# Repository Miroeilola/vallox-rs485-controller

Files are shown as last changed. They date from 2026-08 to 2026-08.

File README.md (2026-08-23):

# Vallox RS-485 Controller

Replacement bus controller for legacy Vallox ventilation units.

<p align="center">
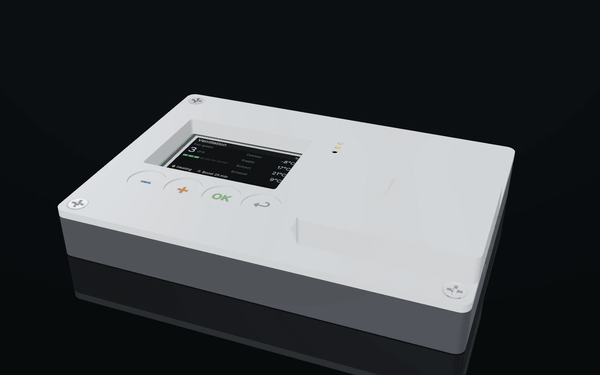
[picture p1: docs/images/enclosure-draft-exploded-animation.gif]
Exploded-view animation: four screws, the cover, the rev A board with the live panel UI, and the base tray separate and reassemble while the camera orbits. A render, not a photograph.
  
</p>

*Render of the rev A board inside the parametric enclosure draft — not a photograph;
one replaces this when a device has been built. Stills in [`docs/images/`](docs/images/),
the [browser simulator](https://miroeilola.github.io/vallox-rs485-controller/) shows
the same board live, and the enclosure draft is generated by
[`mechanical/draft/`](mechanical/draft/).*

<!-- Replace the animation with a photo of the finished device once one exists. -->







> **Status: hardware, rev A.** The board is drawn, placed, routed and sourced —
> not yet ordered or built. The supply-rail measurements (M1, M2a) are done and
> the power stage is final; the browser simulator runs the panel firmware's real
> UI core as WebAssembly; the enclosure exists as a parametric draft that Fusion
> 360 will supersede. Nothing has been verified against a real machine yet. What
> is known, what is only reported, and what still has to be measured is written
> down in [`docs/research/`](docs/research/) and [`docs/measurements/`](docs/measurements/).

## What this replaces

Vallox has built residential heat-recovery ventilation units in Finland since the
1970s, and the SE-series machines are still in service in tens of thousands of
houses. The machine outlives its control panel: the mechanics and the heat exchanger
last decades, the panel's keypad and its electrolytics do not, and panels for the
older models are no longer made.

The machines already carry an RS-485 bus, and everything the panel shows — four
temperatures, fan speed, humidity, CO₂, fault and service state — travels over it
in a six-byte telegram. **This board takes the panel's place**: same five
terminals, same wall, no other hardware, and the machine appears in Home Assistant
or MQTT with no manufacturer cloud service in between.

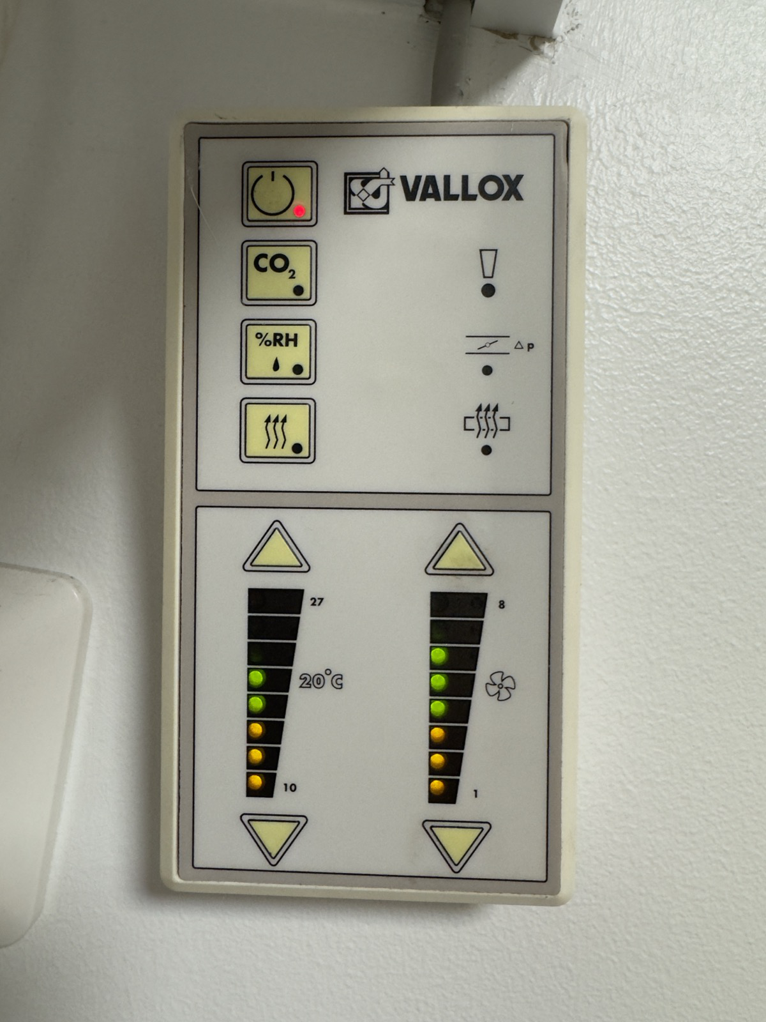
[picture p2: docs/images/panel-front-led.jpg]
The Vallox LED panel being replaced


It is a replacement rather than an addition because the bus does not allow the
addition. The manual says up to three panels may share the bus, and three *Vallox*
panels do — the mainboard keeps them in step. A client that polls on its own
schedule does not join that: tested on the target machine, two controllers override
each other. So the old panel comes off.

That has a consequence worth stating up front, before anyone builds one: **once the
panel is gone, this device is how the ventilation gets controlled.** The machine
keeps running at its last setting if the device fails, and every safety function —
frost protection, over-temperature, defrost — stays in the machine's own firmware
where this device cannot reach it. But nothing changes the fan speed until the
device is working again. Keep the original panel in a drawer.

## Try it in the browser



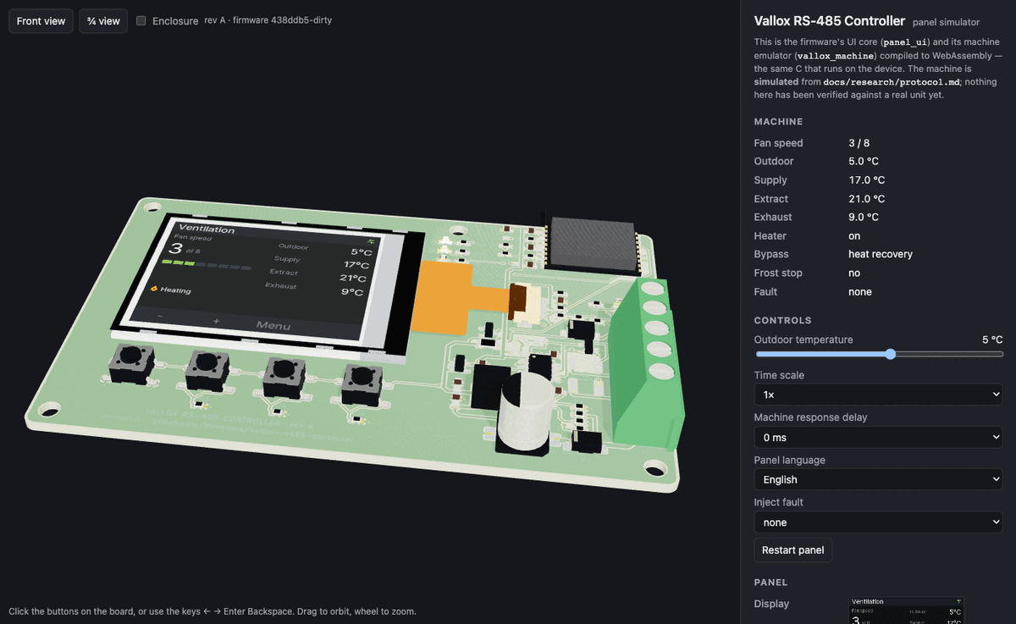
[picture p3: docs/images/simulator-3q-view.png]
Screenshot of the browser simulator: the rev A board rendered from KiCad's 3D export, the panel's dashboard on its display, and the machine side panel. A render, not a photograph.


**https://miroeilola.github.io/vallox-rs485-controller/** — the panel firmware's UI
core and its machine emulator compiled to WebAssembly, drawn on the rev A board's
3D model. Click the buttons, change the outdoor temperature, inject a fault,
watch the bus log, and tick **Enclosure** to see the board inside the draft case. It is the same C that will run on the device
(`firmware/components/panel_ui`), not a look-alike.

The machine behind it is **simulated** from [`docs/research/protocol.md`](docs/research/protocol.md)
and nothing in it has been verified against a real unit yet; the first bus capture
(M3) corrects the document, then the emulator, then the UI. Details and the build
in [`simulator/README.md`](simulator/README.md).

### This is not the first attempt, and that is worth saying

Several people have solved the software side, and solved it well —
[pvainio](https://github.com/pvainio/vallox-rs485),
[kotope](https://github.com/kotope/valloxesp),
[windkh](https://github.com/windkh/valloxserial),
[pecca](https://github.com/pecca/vallox_control),
[mld18](https://github.com/mld18/ioBroker.valloxSerial) and
[Tom-Bom-badil](https://github.com/Tom-Bom-badil/home-assistant_helios-vallox).
The register map here comes from reading their work and is credited in
[`docs/research/sources.md`](docs/research/sources.md).

What none of them ships is hardware. The usual build is a development board, an
RS-485 breakout and a step-down module, loose inside the machine's cable box. This
project adds the missing half: one board that lands on the panel terminals, survives
the wiring mistake the manufacturer warns about in bold, a measured protocol
description with oscilloscope captures rather than a register map you have to read
out of source code, published measurements, an enclosure and a datasheet.

## Specifications

| | |
|---|---|
| Microcontroller | not fixed — ESP32-C3 proposed, see `hardware/docs/decisions.md` |
| Supply voltage | 22 V DC measured at the panel terminal; range not yet measured |
| Current consumption | — (measured, see `docs/measurements/`) |
| Interfaces | RS-485 half duplex, 9600 8N1, Vallox DIGIT protocol · Wi-Fi 2.4 GHz |
| Local interface | 2.0" 320×240 colour IPS, 4 buttons, 3 indicator LEDs — proposed, see `docs/research/user-interface.md` |
| Mounting | Under the machine, replacing the original panel. No footprint to match |
| Dimensions | — |
| Operating temperature | — |
| Enclosure | — |

Every number in this table comes from a measurement or a component datasheet.
Values still marked `—` have not been measured yet.

## Repository layout

| Path | Contents |
|---|---|
| `hardware/` | KiCad 10 project, manufacturing outputs, order packages |
| `firmware/` | ESP-IDF application and reusable components |
| `esphome/` | ESPHome external component (Home Assistant users start here) |
| `simulator/` | Browser simulator: the UI core and machine model in WebAssembly on the board's 3D model |
| `mechanical/` | Enclosure: STEP source, STL for printing, drawings, print profiles |
| `docs/` | Research, measurements, datasheet, images |

## Building one

### 1. Order the board

```bash
git clone --recurse-submodules https://github.com/Miroeilola/vallox-rs485-controller.git
```

Manufacturing files for the released revision are attached to the GitHub release.
The frozen package that was actually sent to the fab is in
`hardware/orders/<rev>-<date>/`, together with what it cost and how long it took.

### 2. Print the enclosure

The enclosure is currently a **parametric draft** ([`mechanical/draft/enclosure.py`](mechanical/draft/enclosure.py)
→ STEP in [`mechanical/step/`](mechanical/step/)), dimensioned from the board file
and verified against the populated 3D model by a boolean interference check —
Fusion 360 will supersede it as the master. See
[`mechanical/README.md`](mechanical/README.md) for material, print settings and
hardware (screws, heat-set inserts).

### 3. Flash the firmware

```bash
cd firmware
idf.py set-target esp32s3
idf.py build flash monitor
```

Pre-built binaries are attached to each release.

### Home Assistant

See [`esphome/`](esphome/) for the external component and a working example
configuration.

## Measurements

Every claim in this repository is backed by a measurement in
[`docs/measurements/`](docs/measurements/): current consumption per operating mode,
rail voltages and ripple, bus signal integrity, and temperature under load.

One report exists so far — the target panel identified and the bus supply measured
at 22 V. It is published with its own gaps marked: the instrument was not recorded
and the load state was not recorded, which is why the regulator's input range is
still an open question rather than a specification.

## What this does not do

- **The display idles dimmed**, and goes to full brightness on a button press.
  Three indicator LEDs stay lit for power, bus activity and fault, and they are
  what answers "is it running" from the doorway.
- **The board works with the display unplugged.** The display is a separate part
  that plugs into an FPC connector after assembly, so a failed or unfitted display
  never means a dead device.
- **Home Assistant is the primary interface.** The local menu covers fan speed,
  the setpoints and diagnostics, and it is a fallback rather than the main event.
- **It is not a safety device and it is not in any safety path.** The machine's
  frost protection, over-temperature thermostats and defrost cycle are in the
  machine's own firmware. This device cannot reach them and cannot disable them.
- **It does not support Vallox MV.** Those units use Modbus and have their own
  interface. This is for the legacy DIGIT RS-485 bus only.
- **It does not support Vallox 130 D** without changes — that model is reported to
  use different register numbers, and no capture from one exists here.
- **It will claim support only for machines a capture exists from.** Other SE-series
  models and Helios KWL EC/ET units are reported to use the same bus, and reported is
  not the same as verified. Which registers a given machine answers is a property of
  that machine.
- **It does not write registers that have not been verified on hardware.** The
  firmware carries an explicit allow-list, it starts with one entry, and a register
  joins it only when a measurement report exists for it. Vallox warns that writing an
  incorrect register or value can damage the unit.
- **It makes no safety or IP-rating claim.** Nothing has been tested for either.
- **Connecting anything to the machine voids the manufacturer's warranty** and is
  your decision, not this project's.

## The machine this was built against

| | |
|---|---|
| Panel replaced | Vallox DIGIT SE LED panel, two 8-segment bar graphs, no LCD |
| Panel bus transceiver | MAX487 — 1/4 unit load, slew-rate limited |
| Terminal | 5-pole screw, `+ − A B M` |
| Supply measured | 22 V DC |
| Machine model | not yet recorded |

Full write-up with photographs:
[`docs/measurements/2026-08-21-panel-identification.md`](docs/measurements/2026-08-21-panel-identification.md).

**Do not wire by colour.** The manufacturer's manual specifies an orange-and-white
NOMAK cable. The machine this was built against has red, blue, green, yellow and
white in those same five terminals. Identify the terminals on your own machine.

## Tools

[`scripts/vlx-decode`](scripts/vlx-decode/) decodes a raw bus capture into
annotated telegrams and a census of the bus. It shares the codec with the
firmware, so it cannot drift from what the device believes.

```bash
cd scripts/vlx-decode && make && ./vlx-decode --demo
```

## Research

Everything known before the design started, with sources and confidence ratings, is
in [`docs/research/`](docs/research/): the
[protocol](docs/research/protocol.md) and its register map, the
[target device](docs/research/target.md) and its panel pinout, the
[measurement plan](docs/research/measurement-plan.md) that has to run before a
schematic is drawn, the [risks](docs/research/risks.md), and the
[component candidates](docs/research/component-candidates.md) with live stock and
prices.

## License

| Path | License |
|---|---|
| `firmware/`, `esphome/`, `scripts/`, `simulator/` | [MIT](LICENSES/MIT.txt) |
| `hardware/`, `mechanical/` | [CERN-OHL-S-2.0](LICENSES/CERN-OHL-S-2.0.txt) |
| `docs/`, README, images | [CC-BY-SA-4.0](LICENSES/CC-BY-SA-4.0.txt) |

See [LICENSE.md](LICENSE.md) for details.

## About

Designed and built by Miro Eilola / [Mironet](https://mironet.fi).
Mironet designs embedded devices like this one on commission — electronics,
enclosure and firmware from specification to production. miro@mironet.fi

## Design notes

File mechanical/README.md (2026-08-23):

# Enclosure

**Current state (2026-08-24): parametric draft, not yet taken over by Fusion.**
`draft/enclosure.py` (build123d) generates the two-part shell from the board file:
`step/enclosure-base-draft.step`, `step/enclosure-cover-draft.step`, and
`draft/screws.py` the M3×8 countersunk screw. `draft/export-enclosure-glb.py`
produces `glb/enclosure.glb` for the browser simulator, and `render/` holds the
scene used for the renders and the exploded-view animation in `docs/images/`.
The draft clears every measured component with margins printed by the script;
membrane-button feel, print tolerances and the final look are Fusion-stage work.

**Fusion 360 is the master for this enclosure.** The STEP files here are the
published source; `.f3d` files are not committed because they require Fusion,
while STEP opens in every CAD system.

| File | Purpose |
|---|---|
| `step/` | Source geometry, exported from Fusion |
| `stl/` | Ready to print |
| `drawings/` | Dimensioned PDF drawings |
| `print-profiles/` | Slicer profiles (`.3mf`) used for the published prints |
| `draft/` | Parametric first-pass scripts, superseded once Fusion takes over |
| `change-requests/` | Requested dimensional changes with measured justification |

## Printing

| | |
|---|---|
| Material | PETG |
| Layer height | 0.2 mm |
| Walls / infill | — |
| Supports | — |
| Estimated time | — |
| Printer used | Bambu |

## Assembly hardware

| Item | Size | Quantity |
|---|---|---|
| Heat-set insert | M3 | — |
| Screw | M3 × — | — |

Heat-set inserts rather than screwing directly into plastic: direct threads survive
two or three openings, inserts survive the life of the device.

## Fit checks

Every enclosure revision is checked against the actual board 3D model before it is
printed — collisions, clearances, standoffs, antenna keep-out, thermal path and
cable routing. Results with measured values are in `fit-check-<date>.md`.

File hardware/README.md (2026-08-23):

# Hardware

KiCad 10 project for Vallox RS-485 Controller.

**Status: rev A schematic drawn and ERC clean; rev A placement done, not routed.** The schematic was drawn
on 2026-08-22 ahead of the power-rail measurements (M1, M2a) so that there is
something concrete to review; the power stage is therefore **provisional** and is
marked as such in the title block. What M1/M2a can change: the regulator part
(TPS54202 vs MP2459), the bulk capacitor value, and whether the backlight runs from
a 5 V intermediate rail (as drawn) or a dedicated boost. Everything downstream of
the 3.3 V rail is independent of those measurements. The measurement plan is
[`../docs/research/measurement-plan.md`](../docs/research/measurement-plan.md);
the parts and the reasoning are in
[`../docs/research/component-candidates.md`](../docs/research/component-candidates.md)
and every choice that needed a reason is in [`docs/decisions.md`](docs/decisions.md).

The schematic is a single A3 sheet drawn with continuous wires — every connection
can be followed by eye, and local labels only name nets, they never carry a
connection. Power rails (+5V, +3V3, GND) use power symbols.

| | |
|---|---|
| Board size | 104 × 66 mm, 2 mm corner radius, 4 × M3 (Ø3.2 mm NPTH) |
| Layers | 2 |
| Copper | 1 oz |
| Finish | HASL lead free (RoHS) |
| Current revision | rev A |

## Open the project

```bash
git submodule update --init          # shared symbol and footprint libraries
open hardware/vallox-rs485-controller.kicad_pro
```

The KiCad project files are named after the project slug (`vallox-rs485-controller.kicad_pro`).
CI expects that name — if the board is named differently, update
`.github/workflows/hardware.yml` to match.

Shared libraries live in `lib/mironet-hw-lib/` and are referenced from
`fp-lib-table` and `sym-lib-table` as `${KIPRJMOD}/lib/mironet-hw-lib/...`.
If symbols appear as missing, the submodule has not been initialised.

## Verification status

| Check | Status | Evidence |
|---|---|---|
| ERC | 0 errors, 1 warning (`lib_symbol_mismatch` on Q1, cosmetic) — 2026-08-22, KiCad 10.0.2 | `output/erc_report.json` |
| DRC (CLI) | 0 errors, 6 warnings (`silk_edge_clearance` on edge-mounted U1/J1/J2), 138 unconnected — placement only, not routed — 2026-08-22, KiCad 10.0.2 | `output/drc_report.json` |
| DRC (GUI, custom rules) | — | run manually before ordering |
| Board built and measured | — | `docs/measurements/` |

## Order packages

Each fabricated revision is frozen under `orders/<rev>-<date>/`: exactly the files
that were sent to the fab, plus what it cost and how long it took. Those folders
are never edited afterwards — corrections go into a new revision.

## Documents

- [`docs/decisions.md`](docs/decisions.md) — component and topology decisions with reasoning
- [`docs/layout-notes.md`](docs/layout-notes.md) — chronological layout log with measured values

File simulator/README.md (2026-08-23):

# Browser simulator

The controller's panel, running in a browser: the firmware's UI core
(`firmware/components/panel_ui`) and its machine emulator (`vallox_machine`)
compiled to WebAssembly with Emscripten, drawn on the rev A board's 3D model
(KiCad's GLB export) with three.js. One C core, four hosts in the design
(ESP-IDF, ESPHome, host tests, browser) — this is the second one that exists,
after the host tests (`docs/design/2026-08-23-panel-simulator-design.md`).

**Live:** https://miroeilola.github.io/vallox-rs485-controller/ — built from
`main` by `.github/workflows/simulator.yml`.

The machine is **simulated** from `docs/research/protocol.md` with a coarse
thermal model. Nothing in it has been verified against a real unit: the
protocol document's confidence classes apply, and the first capture (M3)
corrects the document, then the model, then the UI — in that order.

## What is in the page

| Part | Where | Notes |
|---|---|---|
| 3D board | `src/scene.js` | `public/board.glb` from `kicad-cli pcb export glb` (tracks, zones, pads, silkscreen, mask), meshopt-compressed with gltf-transform to ~0.9 MB (raw 9.7 MB, measured 2026-08-23). Generated, not committed. Procedural studio environment (`RoomEnvironment`), contact shadow. OrbitControls; `Front view` / `¾ view` buttons and keys `F` / `V`. |
| Live display | `src/display.js`, `c/hal_web.c` | `hal_display_flush` converts RGB565 → RGBA into a buffer in WASM memory and keeps the union of dirty rectangles; once per animation frame JS copies that rectangle to a 320 × 240 2D canvas (`putImageData`), which is both the flat view in the side panel and the texture on the display plane. Backlight PWM → texture brightness. |
| Buttons | `src/scene.js`, `src/loop.js` | Hit boxes at SW1–SW4 from `src/board.js` (board coordinates, not GLB node names); keys `← → Enter Backspace`; a press sinks 0.3 mm. The C host holds a press for at least 3 samples so a short click in a slow tab still debounces (`HAL_WEB_MIN_HOLD_SAMPLES`). |
| LEDs | `src/scene.js` | D4 PWR, D6 BUS, D5 FAULT: emissive plane + additive glow sprite. |
| Side panel | `src/panel.js`, `index.html` | Machine state, outdoor temperature −25…+30 °C, time scale 1×/10×/60×, response delay 0/10/200 ms/never, fault injection, panel language, restart; LEDs and backlight; bus log (one frame per line: time, hex, sender → receiver, register/value). |
| Settings | `src/store.js` | `hal_store_*` RAM table mirrored to `localStorage` (`vallox-panel:<key>` = hex) — the language survives a reload, as NVS does. |
| Enclosure | checkbox, disabled | Reserved. When `public/enclosure.glb` exists the checkbox arms itself and toggles a second GLB in the same frame. The STEP does not exist yet. |

Coordinates: the GLB is exported with `--user-origin 0x0mm`, so board x → scene
x, board y → scene +z, height → +y in metres, board top face at y = 1.595 mm.
The display's active area is at board x 10.64–51.44, y 10.8–41.4 mm (from the
DS1 footprint: 30.6 × 40.8 mm AA, footprint at (33.9, 26.1) rotated 90°), module
top 2.05 mm above the board. Pixel (0,0) is the top-left corner as seen from the
front; 0.1275 mm per pixel.

## Build

The board's GLB needs KiCad's 3D library (`KICAD10_3DMODEL_DIR`): a desktop KiCad
has it; the `kicad/kicad:10.0` container does not, so CI runs
`tools/fetch-3d-models.py` first — it downloads only the models the board
references from kicad-packages3D (tag 10.0.5, CC-BY-SA 4.0 with the KiCad
library exception; fetched, not redistributed) and points kicad-cli at them.
Two referenced models do not exist in that library (the HRO USB-C receptacle
and the 1812 fuse) and are drawn without a body, on the desktop too.

```
git submodule update --init   # lib/mironet-hw-lib holds the DS1 display model the GLB export needs
make glb      # public/board.glb from ../hardware (kicad-cli; CI does this in the kicad/kicad:10.0 container)
make wasm     # src/wasm/panel.{js,wasm} with emcc (Emscripten 6.0.8 — brew install emscripten, or emsdk)
make test-c   # native tests of c/hal_web.c and c/sim.c (no browser)
make build    # npm ci + vite build → dist/
make smoke    # Playwright smoke test against dist/ (headless Chromium on SwiftShader)
make test     # all of the above except glb
npm run dev   # Vite dev server on :5173 (needs make wasm first; board.glb optional — a slab is drawn without it)
```

Pinned: three 0.185.1, vite 7.3.6, @playwright/test 1.62.1,
@gltf-transform/cli 4.4.2, Emscripten 6.0.8, Node 22 in CI. WASM ≈ 69 kB
(30 kB gzipped); the page ≈ 680 kB of JS (177 kB gzipped), three.js being most
of it.

## Exported C API

`c/sim_api.h` is the whole surface JS uses: `sim_init/run/time_ms`, the RGBA
framebuffer and dirty rectangle, buttons, LEDs, backlight, machine controls and
readouts (`sim_machine_*`), UI hooks (`sim_ui_*`), the bus log (`sim_log_*`) and
the settings store (`sim_store_*`). Plain C ABI, no Embind. `src/sim.js` wraps
it; nothing else touches pointers.

## Tests

- `test/test_hal_web.c` (native, in CI before the WASM build): ladder levels and
  "lowest pressed wins", minimum-hold release, RGB565 → RGBA conversion and the
  dirty-rectangle union, LEDs/backlight/store, the bus log in both directions
  and its ring, and the e2e through the exported API: `+` three times → fan
  speed +3 and register 0x29, `sim_run` clamping, machine controls, fault →
  FAULT LED, response delay "never" → bus fault and recovery, language + store
  mirror.
- `e2e/smoke.spec.js` (Playwright): the page loads, WASM runs, the display has
  pixels, the bus is up and logged, the GLB loaded, a click on SW2 in the front
  view ×3 moves the fan speed and register 0x29, the keyboard works, the outdoor
  slider reaches the model, an injected fault lights the FAULT LED, no page
  errors. No pixel comparison of the 3D view (spec §4) — the goldens live in
  `firmware/test/host`. Waits are on observable state (`loop.frames`,
  `sim.buttonMv()`), not wall-clock, because a slow runner may render at only a
  few frames per second; `SMOKE_CPU_THROTTLE=8 npx playwright test` reproduces
  a slow runner locally.

## Known gaps

- The enclosure checkbox is disabled until a STEP exists (`mechanical/`).
- GLB materials are KiCad's defaults; no photographic textures.
- The display texture is uploaded whole when any rectangle is dirty
  (`CanvasTexture.needsUpdate`); the dirty rectangle saves the RGB conversion
  and the 2D copy, not the GPU upload. At 320 × 240 that is 307 kB per dirty
  frame and was not measurable as a cost.
- The full page reruns the core at real time only; `sim_run` clamps a sleeping
  tab's catch-up to 200 ms per frame, so after a long sleep the simulated clock
  is behind wall-clock. Intentional.
- No MQTT/Home Assistant mock, no 24 h graphs, no CO₂/RH, no week clock (spec §6).

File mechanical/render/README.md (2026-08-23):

# Render scene for the enclosure draft

Everything under `docs/images/enclosure-draft-*` — the stills and the
exploded-view animation — comes from this directory. three.js scene, KiCad's
own colored GLB for the board, real STEP geometry for the enclosure and screws.

## Regenerate

```bash
# 1. board GLB with colors, tracks, silk and mask (origin at board 0,0)
kicad-cli pcb export glb --subst-models --no-dnp \
  --include-tracks --include-zones --include-pads --include-silkscreen --include-soldermask \
  --output <outdir>/pcb.glb ../../hardware/vallox-rs485-controller.kicad_pcb

# 2. enclosure + screws as GLBs (needs the CAD venv with build123d)
python export-render-glbs.py <outdir>

# 3. UI texture for the display
cp ../../firmware/test/host/golden/dashboard.png <outdir>/ui.png

# 4. serve and open
cp render.html <outdir>/ && cd <outdir> && python3 -m http.server 8931
# open http://localhost:8931/render.html
```

Console API of the page: `setView(az, el, dist, tx, ty, tz)`,
`setVisible({cover, screws, pcb, ...})`, `explodeAll(0..1)`,
`renderFrame(t)` (the 0..1 animation storyboard), `stats()` (fraction of
clipped pixels — keep `clipPct` at 0 before publishing), and
`captureRange(i0, i1, N)` which POSTs numbered PNG frames to
`frame-server.py <www-dir> <frames-dir>` (port 8932).

Animation assembly:

```bash
ffmpeg -framerate 30 -i frames/f%04d.png -c:v libx264 -preset slow -crf 18 \
  -pix_fmt yuv420p -movflags +faststart enclosure-draft-exploded-animation.mp4
```

## Notes

- The KiCad GLB marks **every** material metallic=1/rough=1; the page fixes the
  non-metals on load (see the `pcb` branch in the loader) — without it the board
  renders washed-out.
- The board GLB sits at the board origin; the scene lifts it +4.0 mm (the
  standoff in `../draft/enclosure.py`). The screws GLB is exported pre-placed.
- Lighting follows product-photography practice: one key direction, dim fill,
  cool rim, vignetted backdrop, faint floor reflection. Exposure is verified
  with `stats()`, not by eye.

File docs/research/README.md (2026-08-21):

# Research

Everything learned before the design started, with sources. This folder exists so
that a reader can check the reasoning, and so that a wrong assumption can be traced
back to where it entered.

| File | Contents |
|---|---|
| `target.md` | The device being replaced or interfaced with: model, connectors, measured voltages |
| `sources.md` | Every source with URL, date and a reliability rating |
| `protocol.md` | Claims about the interface, each tagged with its confidence and how it was verified |
| `measurement-plan.md` | What must be measured before the design can be trusted, and safety notes |
| `risks.md` | What could stop the project, and the way around it |
| `component-candidates.md` | Parts considered before the schematic exists, with live stock and the reasoning |
| `user-interface.md` | Display or LEDs: the options costed against live stock, with the power arithmetic and the recommendation |

## Reliability ratings

| Rating | Meaning |
|---|---|
| `manufacturer` | The manufacturer's own document |
| `reverse-engineered` | Someone else's analysis, unofficial |
| `anecdotal` | Forum post, single report, unverified |

Anything not rated `manufacturer` is an open question until it has been measured
on the actual hardware.

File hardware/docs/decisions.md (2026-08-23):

# Design decisions

One entry per decision that would otherwise have to be re-derived later. Newest last.
A decision without a reason is a note, not a decision.

## Template

### YYYY-MM-DD — <what was decided>

**Context.** What problem forced a choice.

**Options.** What was considered, with the numbers that separated them.

**Decision.** What was chosen.

**Reasoning.** Why, with sources: datasheet page, measurement, calculation.

**Consequences.** What this constrains later, and what would make us revisit it.

---

### 2026-08-21 — Bus client, not a panel replacement  — SUPERSEDED same day

**Superseded by "Replace the panel" below.** Kept because the reasoning that led
here was sound and only the premise was wrong: the bus does not tolerate a second
controller. Deleting it would hide that the trade-off was considered.

**Context.** The Vallox DIGIT bus allows up to three control panels. The project
could either replace the factory panel or join the bus alongside it, and the two
lead to different products.

**Options.** Replace the panel: needs a display, a keypad, an enclosure that fits a
wall box, and it takes away the local control the household already uses. Join the
bus: no user interface at all, but the machine keeps working exactly as before if
the board fails.

**Decision.** Join the bus as a fourth client with no local user interface.

**Reasoning.** The failure mode decides it. A ventilation machine in an occupied
house must not depend on this board. As a listener with occasional writes, a failure
is invisible to the household; as the panel, a failure is a house with no
controllable ventilation. It is also the cheaper and smaller board, and the factory
panel stays as the fallback interface.

**Consequences.** The firmware must take a bus address that no factory panel uses,
and it must be passive by default. It also means the device is useless on its own —
the README has to say that it needs a Home Assistant or MQTT installation to be
worth anything.

---

### 2026-08-21 — Power the board from the panel bus

**Context.** The board needs 3.3 V. The panel connector offers approximately 21 VDC
on terminals 1 and 2, which is what the factory panel runs on.

**Options.** Bus power: one cable, one connector, nothing else to install. External
supply: a second cable and a wall wart, and the installation stops being "wire it to
the five terminals the panel used".

**Decision.** Bus powered. Conditional on measurement M2.

**Reasoning.** The whole point of the board over the existing development-board
solutions is that it lands on the panel terminals and nothing else. No source states
how much current the rail can give, so this decision is provisional and M2 is the
gate: if the rail cannot support the radio's average draw plus margin, this is
revisited, and the fallback order is written in risk R2.

**Consequences.** The regulator's quiescent current becomes a selection criterion,
the bulk capacitor is sized from the transmit burst rather than from habit, and the
firmware's Wi-Fi duty cycle becomes an electrical parameter rather than a
convenience setting.

**Update, same day.** Photographs of the original panel show it running from the
bus through a TO-220 **linear** regulator on a folded heatsink. A linear regulator
that needs a heatsink from 22 V is burning on the order of a watt, so the rail was
built to source at least the panel's own draw — sixteen LEDs, a microcontroller
and a transceiver — through that drop. That is a prior, not a number, and M2 still
has to produce the number. It points the right way, and it hands the project a
comparison worth publishing: a switching regulator should draw less from the bus
than the panel it replaces, while doing more.

---

### 2026-08-21 — Survive reversed wiring by design

**Context.** The Vallox Digit2 SE manual prints, in bold, next to the panel terminal
table: *"(+) johdon virheellinen kytkentä tuhoaa ohjainpaneelin!"* — miswiring the
positive conductor destroys the control panel. That is the manufacturer describing
its own product's behaviour.

**Options.** Accept the same behaviour and warn in the documentation. Or design so
that a wiring mistake costs nothing.

**Decision.** The board survives reversed supply polarity and 21 V applied to either
data line, and this is verified on the bench before the board is connected to a
machine.

**Reasoning.** A replacement that fails the same way as the part it replaces has not
improved anything, and this is the single most likely mistake an installer will
make — the failure the manufacturer had to print a warning about. It costs a
three-cent Schottky in series with the supply and about seven cents of fuse and TVS
on the data lines. That is not a trade-off, it is a rounding error.

**Consequences.** Series elements in both data lines, which slightly reduces the
differential swing, and a forward drop on the supply, which slightly reduces the
input headroom. Both are accounted for in the regulator's input range. The bench
test for this becomes a published measurement.

---

### 2026-08-21 — Hardware-timed driver enable, not an auto-direction module

**Context.** The community guide for connecting a Vallox to Home Assistant reports
that RS-485 adapters without automatic direction control make the machine display
`Väylävika`, a bus fault, and recommends buying a module with a direction timer.

**Options.** A transceiver module with a one-shot timer on the driver-enable pin, a
software-toggled GPIO, or the ESP32 UART's own RS-485 half-duplex mode, which drives
the enable from the RTS pin in hardware.

**Decision.** The UART peripheral's RS-485 half-duplex mode, driving the transceiver's
DE/RE pins from RTS.

**Reasoning.** The reported fault is a timing fault: the driver is released too late
and steps on the next talker, or too early and truncates the last stop bit. A
one-shot timer is tuned for one baud rate and is approximate. A software GPIO is at
the mercy of task scheduling. The peripheral does it exactly, for free, and the
timing is deterministic.

**Consequences.** DE and RE are tied together and driven from one pin, which fixes
the pin budget. The real gap between frames is measured in M4 before any transmit
code runs, so this decision gets checked against evidence rather than assumed to work.

---

### 2026-08-21 — Proposed: ESP32-C3 instead of the scaffolded ESP32-S3  — MODULE VARIANT REVISED 2026-08-22

**Context.** The project was scaffolded with the workspace default, ESP32-S3. The
workload is one 9600 baud UART, a Wi-Fi client and MQTT.

**Options.** ESP32-S3-WROOM-1-N4 at roughly $3.80, ESP32-C3-MINI-1-N4 at $2.79
(C2838502, 16 416 in stock on 2026-08-21), or a bare C3 chip with a PCB antenna at
roughly $1.

**Decision.** **Proposed**, not yet taken: ESP32-C3-MINI-1-N4.

**Reasoning.** Nothing in the workload uses a second core, PSRAM, or the S3's
peripherals. The C3 has the same native USB Serial/JTAG, so neither part needs a
USB-to-UART bridge. It is about a dollar cheaper and idles lower, and the gating risk
on this project is the current the bus rail can supply — so the lower-power part is
also the lower-risk one. A pre-certified module rather than a bare chip, because a
design other people are told to build should not hand them an uncertified radio.

This stays *proposed* because M2 could push it further. If the rail turns out to be
much weaker than assumed, the answer is not a different ESP32 but a different radio,
and deciding now would only have to be undone.

**Consequences.** `project.yaml` and the firmware target still say `esp32s3` and are
left alone until M2 closes this. Recorded here so the contradiction is visible rather
than forgotten.

**Update, same day.** The local interface grew a 320 × 240 display, four buttons
and three indicator LEDs, and the C3's pin budget went from comfortable to
twelve-of-thirteen — and only because the buttons were moved onto a resistor
ladder. It still fits, and the ladder is a reasonable design rather than a
workaround, but the margin is gone. Whichever way M2 pushes the power question,
the pin count is now a second thing weighing on the same decision. See the button
entry at the end of this file for the budget.

---

### 2026-08-21 — Isolation deferred to a measurement, not chosen up front

**Context.** The project's premise mentions a galvanically isolated RS-485 front
end. On a board whose only external connection is the bus it draws power from, an
isolation barrier inside the board protects nothing during normal operation — the
power crosses it too.

**Options.** Non-isolated, with protection on the bus lines. Or an isolated
transceiver plus an isolated DC-DC carrying the board's whole supply, about $1.60
more per board.

**Decision.** Deferred to measurement M1: whether the 21 V panel rail is isolated
from mains.

**Reasoning.** The Vallox internal wiring diagram labels the supply transformer as
an autotransformer *with a protective-voltage winding*, which reads as the panel rail
being SELV. That reading comes from a low-resolution scan and is the weakest claim in
the research that actually matters. If it holds, isolation buys nothing during
operation and the honest thing is a cheaper board plus a documented rule about not
connecting USB while wired to the machine. If it does not hold, isolation is not an
upgrade, it is mandatory — and so is a rethink of whether this device should exist in
a form a homeowner wires themselves.

**Consequences.** The schematic is not drawn until M1 is reported. Both variants are
costed in `docs/research/component-candidates.md` so the decision is a measurement
away, not a redesign away.

**Update, same day.** The original panel is not isolated either — its transceiver
and its logic sit on the bus's own ground, behind a linear regulator fed from the
supply pair. So the non-isolated variant is exactly what has hung on this wall for
two decades, which is an argument, though not a proof: the panel also has no USB
socket and nothing else to tie it to another ground. The earth measurement in M1
still decides, and it now decides mainly what the documentation is allowed to say
about connecting a laptop to the device while it is wired to the machine.

---

### 2026-08-21 — Replace the panel

**Supersedes "Bus client, not a panel replacement" above.**

**Context.** The earlier decision assumed this board could join the bus alongside
the factory panel, on the strength of the manufacturer's statement that up to
three panels are allowed. Prior testing on the target machine says otherwise:
**with two controllers on the bus, they override each other.** That is first-hand
evidence from the machine this project is built against, and it beats a line in a
manual.

The likely explanation is that three *Vallox* panels work because the mainboard
broadcasts state to the whole panel group and the panels mirror it rather than
compete. A third-party client that polls on its own schedule is not part of that
choreography. Either way the outcome is the same.

**Options.** Coexist with the panel — ruled out by the test. Replace the panel and
take its address. Or sit between the machine and the panel as a repeater, which
means two transceivers, a store-and-forward layer, and a device that can break the
panel when it fails.

**Decision.** The original panel comes off the wall. This device goes on in its
place, on the same five terminals, as the only controller on the panel side.

**Reasoning.** It is what the bus allows. It also removes a whole class of
problems that the coexistence design carried: no address negotiation, no listening
for a quiet window before transmitting, no risk of provoking a bus fault in normal
operation.

**Consequences, and they are not small.**

1. **The device is now load bearing.** The earlier design could fail invisibly
   and the household would not notice. This one cannot: if it stops, nothing
   controls the ventilation. The machine keeps running at its last setting, which
   is the good news, but nothing can change it.
2. **Everything the panel could set has to be settable here.** Heating setpoint,
   bypass, pre-heat, supply-fan stop, fan speed limits. The one-entry write
   allow-list stays as the mechanism, but its content has to grow — one register
   at a time, each with a measurement report behind it.
3. **Local controls become a real question**, because removing the panel removes
   the only way to change fan speed without a network. Written up in
   `docs/research/target.md`; the recommendation is speed up, speed down and a
   visible indication of speed, at minimum.
4. **The bus survey in the firmware changes purpose.** It no longer picks a free
   address. It verifies that nothing else is talking on the panel side, which is
   a precondition rather than a convenience.
5. **The enclosure replaces a panel, but not a living-room one.** The original is
   mounted under the machine, in a technical space, with no footprint to match and
   nothing to cover up. The manufacturer's 90 × 110 × 23 mm is a reference point,
   not a requirement, and the replacement is free to be whatever shape suits its
   contents.

---

### 2026-08-21 — Match the original's bus loading and slew rate

**Context.** The original panel's transceiver was read off the board in the
photographs: a **MAX487**. That is a 1/4-unit-load, slew-rate-limited part —
48 kΩ receiver input impedance, up to 128 nodes, specified to 250 kbps.

**Options.** Fit the cheapest 3.3 V transceiver in the assembler's basic
inventory, or match the characteristics the machine was designed against.

**Decision.** The replacement presents a bus load no heavier than 1/4 unit load
and uses a slew-rate-limited driver. Candidate: **THVD1400DR** — 1/8 unit load,
integrated open, short and idle bus fail-safe, 500 kbps slew-rate limited class,
3–5.5 V, bus pins rated −16 V to +16 V absolute maximum, ±12 kV IEC contact ESD
(TI datasheet SLLSF78B).

**Reasoning.** Three things follow from the original's choice, and none of them
are guesses:

- The machine's driver was specified against a 1/4-unit-load panel. Replacing it
  with something heavier changes what that driver sees. Replacing it with
  something lighter cannot.
- The original deliberately limits its slew rate at 9600 baud. Fitting a 10 Mbps
  part on a cable that runs through a house would raise emissions for no benefit.
- The integrated fail-safe removes two bias resistors **and** removes an open
  question from the design: whether the machine biases the bus stops mattering for
  the receiver's idle state.

It costs about 14 cents more than the cheapest basic part, and it is an Extended
part rather than a Basic one.

**Consequences.** The bus pins are still only rated to ±16 V, so 22 V landing on
a data line would exceed them. The resettable fuse and the SM712 clamp stay — the
transceiver choice does not replace the protection, it sits behind it.

If the transceiver is ever swapped for the cheaper Basic part on cost grounds,
that substitution has to be checked against all three requirements above, not just
against the pinout.

---

### 2026-08-21 — Local interface: a sleeping OLED, three buttons, three LEDs — REVISED same day

**Context.** With the panel removed, the machine has no local interface at all.
The panel it replaces sits under the machine in a technical space, so there is no
size to match and no aesthetic to preserve — the question is purely what the
interface is for.

**Options.** Costed against live JLCPCB stock in
`docs/research/user-interface.md`: an LED bar and buttons at about $0.36, a 0.96"
128×64 OLED at about $2.55 for the finished device, a 1.14" colour TFT at about
$3.05 with an unresolved backlight question, and e-paper, which is not in the
fab's catalogue and needs ambient light in a room that has none.

**Decision.** A 0.96" OLED that sleeps and wakes on a button press, three tactile
switches, and three always-on indicator LEDs for power, bus activity and fault.

**Reasoning.** Three things, in order of weight.

1. **Parity.** The panel being removed could set the heating setpoint from an
   eight-step bar graph on the wall. Matching that with LEDs means rebuilding a
   2001 keypad — twenty LEDs and eight buttons. A display and three buttons is a
   menu, and it is cheaper than the replica.
2. **Diagnostics.** Wi-Fi state, IP address, bus frame and error counters, the
   last reset reason. On a display that is a screen; on LEDs it is a blink code,
   and blink codes are how a device becomes hostile. The firmware rules already
   require this output to exist.
3. **It barely touches the board.** $0.30 of connector and switches is assembled;
   the display is a bare panel plugged in afterwards. The same board takes either
   choice, so this decision stays reversible far longer than most.

Sleeping is not a power saving, it is a lifetime decision. Passive-matrix OLED is
specified to half brightness in the region of 10 000 hours for lit pixels, which
is fourteen months of continuous operation, and a static fan-speed readout would
burn in well inside the life of the appliance. Off by default, thirty seconds on a
keypress, removes that entirely.

**The argument against, kept because it is good.** The panel being replaced has
LEDs that outlived its own electrolytic capacitors, and they are still lit in the
photographs after about twenty-five years. An OLED will be the first thing on this
board to fail, and a sleeping display is dark exactly when someone glances over to
check the machine is running. That argument loses only because Home Assistant is
the primary interface here and the local one is a fallback — and if that
assumption ever changes, so does this decision.

**Consequences.** The enclosure needs a display window, which is the hardest
feature to print well on an FDM part. The firmware acquires a menu, which is scope
that competes with the protocol work, so it is built last and kept small. The
three indicator LEDs stay regardless, because "is it alive" should not require
waking anything.

**Revised, same day — see the entry below.** The 0.96" size was chosen before
anyone worked out how much text fits on it. It fits eight characters by three
lines at arm's length, which is not a menu, and the decision above was made on
the strength of being able to present a menu. Superseded rather than deleted,
because the failure mode is instructive: the part was selected on price and
category before the requirement was quantified.

---

### 2026-08-21 — Local interface, revised: a 2.0" colour IPS

**Supersedes the entry above.** The reasoning there stands; only the size and the
technology change.

**Context.** The previous entry chose a 0.96" OLED because a display was needed to
present a menu of named setpoints. Nobody had worked out how much text a 0.96"
display actually shows.

**The number that changed it.** Legibility is angular: a comfortable character
subtends about 20 arcminutes, which is a character height of roughly viewing
distance ÷ 170. At arm's length — 50 cm, because someone walks up and presses a
button — that is 2.9 mm.

| Display | Chars × lines at 50 cm | $ | $ per 100 mm² |
|---|---|---|---|
| 0.96" OLED | **8 × 3** | 2.31 | 0.98 |
| 1.3" OLED | 11 × 4 | 5.33 | 1.23 |
| 1.54" OLED | 13 × 5 | 6.46 | 1.05 |
| **2.0" IPS** | **16 × 9** | **3.77** | **0.30** |
| 2.8" TFT | 22 × 12 | 5.26 | 0.21 |

Eight characters by three lines cannot show `SUPPLY FAN STOP` or a scrolling list
of settings. It shows a fan speed and a temperature, which is what the LED bar it
replaces already did — for a tenth of the price.

**Decision.** `HS20HS072RX`, 2.0" 320 × 240 colour IPS, ST7789 over SPI, LCSC
C5329582, $3.77, 657 in stock, active area 40.8 × 30.6 mm, −20…+70 °C. Three
tactile switches and three indicator LEDs as before.

**Reasoning.**

1. **Size.** 16 × 9 characters is a menu, a status page and a diagnostics screen.
   8 × 3 is a readout.
2. **Value.** Colour TFT costs $0.21–0.30 per 100 mm² and mono OLED costs about
   $1.00 and gets worse with size. The 2.0" is 5.3× the screen area of the 0.96"
   for $1.46 more. Paying more for the smaller screen is not a trade-off.
3. **No burn-in.** This removes the sleep requirement and with it the objection
   that a sleeping display is dark exactly when someone glances at it. The
   backlight idles dimmed and goes to full on a keypress.
4. **Viewing angle.** IPS, full angle, on a panel mounted under a machine and
   therefore read from below or from the side.

**Consequences, and one of them is open.**

- **The backlight needs a driver.** The datasheet gives four white LEDs in
  parallel at 80 mA typical. Around 3.0–3.2 V forward, there is no headroom from
  3.3 V and parallel LEDs cannot share one resistor without current hogging.
  Either a boost driver at about $0.30 plus an inductor, or a **5 V intermediate
  rail** with a PWM-dimmed constant-current sink at about $0.05. The second is
  cheaper and better but it changes the whole power chain, so **it is decided
  together with M2a, not before.**
- Backlight power becomes the largest single load: 80 mA at 5 V is 0.4 W against
  an estimated 1.1 W budget, or 0.08 W dimmed to 20 %. Another reason M2a matters.
- The local interface now costs about $4.15 of a roughly $8.80 parts total. That
  is a real fraction and it is stated plainly in `docs/research/user-interface.md`
  rather than softened.
- The board must work with the display unplugged, and the three indicator LEDs
  stay, so that a failed or unfitted display never means a dead device.

---

### 2026-08-21 — Buttons: four tactile switches on a resistor ladder  — PART REVISED 2026-08-22

**Context.** The bill of materials has carried `TS-1187A-B-A-B` since the LED
sketch, but it was carried rather than chosen — nobody had decided how many
buttons, what force, what plunger height, how they are actuated through a printed
enclosure, or how they connect to a microcontroller whose pins are nearly all
spoken for.

**How many, and which.** Four: `−`, `+`, `OK`, `←`.

On the home screen `−` and `+` change fan speed directly, with no menu. That is
the daily action and it is what the original panel had dedicated arrows for. `OK`
enters the settings menu and confirms, `←` backs out.

Three buttons would work if `←` became a long press on `OK`. It is rejected
because long-press is a convention that has to be taught, and this device will be
operated twice a year by somebody who has forgotten. The fourth button costs one
resistor and one hole.

**The pin budget is what decided the wiring, and it is tighter than expected.**
ESP32-C3-MINI-1 exposes GPIO0–10 and GPIO18–21: fifteen pins, of which GPIO18 and
GPIO19 are USB-Serial-JTAG and giving them up means giving up USB.

| Function | Pins |
|---|---|
| RS-485 TX, RX, DE | 3 |
| Display SPI: SCK, MOSI, CS, DC | 4 |
| Display reset | 0 — RC from the 3.3 V rail |
| Backlight PWM | 1 |
| Indicator LEDs | 3 |
| **Buttons** | **1** |
| **Total** | **12 of 13** |

Four buttons on four GPIOs would need sixteen pins and does not fit. So the
buttons go on a **resistor ladder into one ADC channel**: four resistors, one pin,
one spare left over.

ADC1 only — GPIO0 to GPIO4 — because ADC2 is unusable while Wi-Fi is running.
GPIO2 is a strapping pin, and GPIO0/GPIO1 are the 32 kHz crystal pins if one is
ever fitted, so the ladder lands on **GPIO3 or GPIO4**. Neither is a strapping
pin, so a button held at power-up cannot change the boot mode — which is what
makes "hold `←` while powering up" a safe way to trigger a factory reset.

**The part.** `TS-1187A-B-A-B`, LCSC **C318884**: JLCPCB *Basic*, $0.0197,
1 683 297 in stock, 5.1 × 5.1 mm SMD, 1.6 N, 100 000 cycles, gold contacts,
−30…+85 °C.

The reason this part rather than another is that **the whole TS-1187A family
shares one 5.1 × 5.1 mm four-pad footprint** and differs only in plunger height
(1.5 to 3.0 mm) and force (1.6 N or 2.6 N). The board can be laid out now and the
height and force chosen when the enclosure exists, with no board change. In stock
today: 1.5 mm/1.6 N (Basic, $0.020), 1.7 mm/2.6 N ($0.040), 2.5 mm/2.6 N ($0.040),
3.0 mm/2.6 N ($0.047).

**Actuation through the enclosure — a mechanical decision, named here so it is not
forgotten.** Three ways, in order of preference:

1. **A thin flexure printed into the front panel**, 0.6–0.8 mm of PETG over each
   switch. No holes, no loose parts, and nothing for dust to get through — which
   matters next to a machine whose whole job is moving air through filters. Needs
   a short plunger and a light switch, because the flexure adds its own force, so
   it points at exactly the 1.5 mm / 1.6 N part above.
2. Separate printed plungers in through-holes. Four loose parts, a tolerance stack
   and a dust path.
3. A 3 mm plunger poking through the front. Simple, but the front wall plus the
   air gap has to come to under 3 mm and the stem is exposed.

**No BOOT or RESET buttons.** The C3's native USB-Serial-JTAG resets the chip and
enters download mode over USB with no buttons at all. EN and GPIO9 get test pads
instead: no enclosure holes, no cost, and nothing on the front panel that is not
for the user.

**Capacitive touch was considered and rejected**, for two reasons and the second
is the real one. **ESP32-C3 has no capacitive touch peripheral** — ESP32, S2 and
S3 do, C3 does not — so it would need external touch ICs at about $0.06 a channel.
More importantly, this is the only control the household has for its ventilation.
A control with no tactile feedback, in a space with dust and the possibility of
condensation, that can false-trigger or stop responding for reasons the user
cannot see, is the wrong risk to take for the sake of a smooth front panel.

**A rotary encoder was considered and rejected for now.** Turning through a
nine-line list is a better interaction than pressing `−` sixteen times, and if the
menu turns out deep it should be reconsidered. Against it: `EC11L1525G01` is $1.27
against $0.08 for four switches — sixteen times the price of the entire button set
— it is through-hole and so carries per-joint assembly cost, it needs a shaft, a
knob and a large hole, and a detented encoder is the most wear-prone mechanical
part that could be put on a board meant to last as long as the machine.

**Consequences.**

- Four resistors and one ADC channel instead of four GPIOs. Debouncing is done on
  a converted value rather than an edge, and the firmware has to reject readings
  that fall between ladder steps rather than round them to the nearest button.
- The ladder cannot see two buttons at once. Nothing in this interface needs it.
- **This tightened the case for revisiting the microcontroller.** On an ESP32-S3
  there are pins to spare and the buttons would be four plain GPIOs. The C3 fits,
  but with one pin left, and that is worth weighing when M2a closes the power
  question and the C3-versus-S3 decision is finally taken.

---

### 2026-08-22 — Library coverage is a part selection criterion

**Context.** Parts had been selected on requirement, price, stock and JLCPCB
Basic/Extended class. Nothing in that list asks whether a KiCad footprint and a 3D
model already exist. Checking the shortlist against the installed libraries found
that the most important footprint on the board — the microcontroller module — had
neither.

**Decision.** Existing library coverage is a selection criterion alongside the
others: prefer the part that already has a footprint **and** a 3D model, whenever
one exists that meets the electrical and mechanical requirement.

**Reasoning.** A drawn footprint has to be validated against IPC-7351 and against
the manufacturer's land pattern, and a wrong one is found at assembly. A 3D model
is a precondition for the enclosure fit check that this workspace requires before
anything is printed — and a missing model is not visible as a problem until the
enclosure has already been designed around a guess.

**How it is applied.** Three cases, three different answers:

1. **Footprint and model both exist** — use the part.
2. **Footprint exists, model missing** — this is not a reason to change the part.
   Obtain the manufacturer's STEP, or build one, and put it in `mironet-hw-lib`.
3. **Neither exists** — the strongest reason to prefer a different part. If the
   part is kept anyway, the library work is recorded as work, not assumed.

The rule does not override an electrical or mechanical requirement. If library
coverage is only available on the wrong part, the right part wins and the library
is extended.

**Where to check.** On disk, not from memory:

- footprints: `<KiCad>/SharedSupport/footprints/<lib>.pretty/<name>.kicad_mod`
- models: `<KiCad>/SharedSupport/3dmodels/<lib>.3dshapes/<name>.step`

KiCad 10 ships `.step` only, not `.wrl`. Two MCP tools give false negatives here
and neither may be used as evidence that something is missing:
`lib_search_3d_models` returns nothing for everything because it searches the
footprint directory, and `lib_search_footprints` missed footprints that are
present on disk.

**Consequences.** Two parts changed as a direct result, recorded below. Two more —
the USB-C receptacle and the display — keep their part and gain a library task
instead.

---

### 2026-08-22 — ESP32-C3-WROOM-02 instead of ESP32-C3-MINI-1

**Context.** The proposal above chose `ESP32-C3-MINI-1-N4` and named
`ESP32-C3-WROOM-02-N4` as a design-time alternative on a different footprint.
Two things have changed since it was written, and both point the same way.

**Options.**

| | ESP32-C3-MINI-1-N4 | ESP32-C3-WROOM-02-N4 |
|---|---|---|
| LCSC | C2838502 | C2934560 |
| Price, 2026-08-21 as recorded | $2.79 | $3.11 |
| Price, 2026-08-22 live | **$3.84** | **$2.89** |
| Stock | 25 989 | 2 255 |
| KiCad footprint | none | `RF_Module:ESP32-C3-WROOM-02` |
| KiCad 3D model | none | present |
| Module size | 13.2 × 16.6 mm | 18.0 × 20.0 mm |

**Decision.** `ESP32-C3-WROOM-02-N4`, LCSC C2934560.

**Reasoning.** The original argument for the MINI was price, and the price has
inverted: the module is now $0.95 cheaper than the part that was chosen for being
cheaper. Independently of that, the MINI-1 is the only part in the design with
neither a footprint nor a 3D model, and it carries the largest and most
consequential land pattern on the board.

The size penalty costs nothing here. The panel is mounted under the machine in a
technical space, and it is already recorded that there is no enclosure footprint to
match and nothing to cover. 4.4 mm of extra width buys a verified land pattern.

Both are the same silicon: ESP32-C3, 4 MB flash, and the pin budget above is
unchanged — the WROOM-02 exposes the same GPIO0–10 and GPIO18–21.

**Consequences.**

- Stock is 2 255 against 25 989. That is enough for any realistic batch but it is
  not the same margin, and it is re-checked at the pre-order gate.
- The MINI-1 becomes the second source rather than the first, and it is a
  design-time alternative only: different footprint, so it is not a drop-in.
- The board outline grows by roughly 4 mm in each direction in the module area.
  Layout has not started, so nothing is lost.
- The antenna keep-out moves with the module and is re-derived from the WROOM-02
  datasheet, not carried over.

---

### 2026-08-22 — Buttons revised: 6 × 6 mm gullwing instead of TS-1187A

**Supersedes the part choice in "Buttons: four tactile switches on a resistor
ladder" above.** Everything else in that entry stands: four buttons, the `−` `+`
`OK` `←` assignment, the resistor ladder into one ADC1 channel, no BOOT or RESET
buttons, and the rejection of capacitive touch and of a rotary encoder.

**Context.** `TS-1187A-B-A-B` was chosen partly because the whole TS-1187A family
shares one footprint, so the board could be laid out before the enclosure existed.
That argument was right. What it missed is that the family has a KiCad footprint
but **no 3D model at all**, which defers a problem into the one activity that
cannot absorb it — fitting an enclosure to a real board.

**Options.** Restricted to 4-pad SMD tactile switches that have both a footprint
and a 3D model in the installed libraries. That is the 6 × 6 mm gullwing family,
which resolves to two land patterns that are **not interchangeable**:

| Footprint | Pad span | 3D model |
|---|---|---|
| `SW_SPST_PTS645Sx43SMTR92` | 7.96 × 4.5 mm | present, H4.3 mm |
| `SW_Push_1P1T_NO_E-Switch_TL3301NxxxxxG` | 9.10 × 4.5 mm | present, H4.3 mm |

Parts on the 6 × 6 gullwing pattern, read live 2026-08-22:

| LCSC | Part | Height | Force | Cycles | Stock | $/pc |
|---|---|---|---|---|---|---|
| C879454 | K2-6639SP-A4SC-04 | 4.3 mm | 2.5 N | 1 000 000 | 54 370 | 0.0456 |
| C2837531 | KH-6X6X5H-STM | 5.0 mm | — | 80 000 | 720 195 | 0.0188 |
| C7470150 | ZX-QC66-4.3TP | 4.3 mm | 2.6 N | 100 000 | 65 369 | 0.0288 |
| C221877 | PTS645SL50SMTR92LFS | 5.0 mm | **1.3 N** | — | 9 410 | 0.2831 |

For comparison, the part being replaced: TS-1187A-B-A-B, C318884, 5.1 × 5.1 mm,
1.5 mm high, 1.6 N, 100 000 cycles, JLCPCB *Basic*, $0.0197, 1 683 297 in stock,
footprint present, **no 3D model**.

**Decision.** Lay the board out on the **PTS645 land pattern**
(`SW_SPST_PTS645Sx43SMTR92`). Fitted part: **PTS645SM43SMTR92LFS**, LCSC
**C221880** — C&K's own part, 1.6 N, 4.3 mm, −20…+85 °C, 1 421 in stock, $0.532.

*Recorded earlier the same day as `K2-6639SP-A4SC-04` (C879454, $0.0456), and
changed when price was explicitly removed as a constraint. The clone is kept below
as the cost-reduction option, because it is the right answer if a batch ever makes
$0.49 a button matter.*

**Reasoning.**

1. **It is the part the KiCad footprint was drawn for.** `SW_SPST_PTS645Sx43SMTR92`
   is C&K's own land pattern, taken from C&K's datasheet. Fitting the genuine part
   removes the pad-span question entirely rather than answering it — see the note
   on that below, which this decision retires.
2. **1.6 N restores the force the flexure wanted.** The superseded entry chose
   1.6 N because a printed flexure adds its own force. The 6 × 6 clones are
   2.5–2.6 N; this part is 1.6 N. The compromise disappears instead of being
   deferred.
3. **The 3D model is exact, not approximate.** This part is 4.3 mm high and the
   KiCad model is the 4.3 mm variant. The cheaper KH-6X6X5H is 5.0 mm, which
   leaves the model 0.7 mm wrong in exactly the dimension that sets front-panel
   thickness and clearance. A model that is nearly right is worse than none,
   because it will not be questioned.
4. **A real second source.** C&K is stocked by Digi-Key, Mouser and Farnell. Every
   6 × 6 clone considered here is available from LCSC and nowhere else, which is a
   single point of failure on a part fitted four times per board.
5. **6 × 6 mm is a larger target than 5.1 × 5.1 mm**, pressed through a printed
   front panel. Larger is better here, not worse.
6. The same argument that favoured the TS-1187A family still holds and holds
   wider: one land pattern carries plunger heights from 4.3 mm to 9.0 mm — 4.7 mm
   of choice against the TS-1187A family's 1.5 mm.

**Other parts on the same pads**, if the enclosure or a cost target later argues
for one. The board does not change for any of them:

| LCSC | Part | Force | Height | Stock | $/pc |
|---|---|---|---|---|---|
| **C221880** | **PTS645SM43SMTR92LFS** | **1.6 N** | **4.3 mm** | 1 421 | **0.532** |
| C221871 | PTS645SK43SMTR92LFS | 2.6 N | 4.3 mm | 2 152 | 0.482 |
| C221877 | PTS645SL50SMTR92LFS | 1.3 N | 5.0 mm | 9 410 | 0.283 |
| C879454 | K2-6639SP-A4SC-04 | 2.5 N | 4.3 mm | 54 370 | 0.046 |
| C7470150 | ZX-QC66-4.3TP | 2.6 N | 4.3 mm | 65 369 | 0.029 |

The 1.3 N part is lighter still but 5.0 mm tall, so its 3D model is 0.7 mm off.
The clones are an order of magnitude cheaper and carry both the pad-span question
and single-sourcing.

**Consequences.**

- **Basic status is lost.** Every 6 × 6 option is Extended; TS-1187A was Basic.
  That is roughly $3 of feeder setup per order, not per board — about $0.30 a board
  across ten boards.
- Parts cost for the button set rises from $0.08 to **$2.13** per board. On a board
  whose parts come to about $4.85 that is a 44 % increase for four switches, and it
  is accepted deliberately: it buys the correct force, an exact model, a verified
  land pattern and a second source, on the only control the household has.
- Board area per button grows from 5.1 × 5.1 mm to 6 × 6 mm, four times over.
- **The pad-span verification that this entry originally listed as blocking is
  retired.** It existed because a clone's land pattern could not be inferred from a
  catalogue package string. Fitting C&K's own part makes KiCad's footprint and the
  part's datasheet the same document. If a clone is ever substituted for cost, the
  check comes back with it.
- The switch is 4.3 mm high against 1.5 mm. The board-to-front-panel distance
  changes accordingly and is an input to the enclosure, not a consequence of it.

---

### 2026-08-22 — USB-C stays inside the enclosure

**Context.** The USB-C receptacle `TYPE-C-31-M-12` (C165948) has an exact KiCad
footprint but no 3D model, and the search for a replacement that has both found
only one part in JLCPCB's catalogue: Amphenol `12401610E4#2A` (C5119948) at $1.334
against $0.161, 24 pins of USB 3.2 against 16 of USB 2.0, for a port this design
uses as a bench connection. Changing the part to gain a model is the wrong trade.

**Decision.** Keep `TYPE-C-31-M-12`, and place it **inside the enclosure** with no
opening in the wall. Reaching it means opening the box.

**Reasoning.** The port exists for bench work: first flash, console, and recovery.
None of those happen with the device installed under the machine. An opening in the
wall would add a dust path into an enclosure that lives beside a fan moving filtered
air, and dust ingress is the failure this enclosure is most exposed to.

That also settles what the missing 3D model is for. It is no longer needed to place
an opening to ±0.5 mm; it is needed for internal clearance — that the lid closes
over the receptacle and that nothing lands on top of it. That is a lower accuracy
requirement, and it does not change the decision to model the part, only its
urgency.

**Consequences.**

- **Field firmware updates are OTA-only.** This is already required by the
  workspace firmware rule, but it stops being a convenience and becomes the only
  path. Rollback on a failed update has to work, because the fallback is a
  screwdriver.
- **Recovery from a bad flash means opening the enclosure.** Combined with the
  earlier decision to fit no BOOT or RESET buttons and rely on the C3's native
  USB-Serial-JTAG, there is no way to recover a bricked device without taking it
  off the wall. Accepted: the alternative is a hole, a button, or both, on a front
  panel that should carry nothing that is not for the user.
- The enclosure needs no USB cutout, no gasket around one, and no strain relief for
  a cable that is never connected in service.
- Test pads for EN and GPIO9 remain worth having, and are now the only external
  electrical access besides the terminal block.

---

### 2026-08-22 — Schematic rev A drawn before M1/M2a, power stage marked provisional

**Context.** The plan was not to draw a schematic before the rail measurements.
Miro asked for something concrete in KiCad now. Roughly two thirds of the design
does not depend on those measurements at all, and the third that does can be
redrawn as a component swap rather than a topology change.

**Decision.** Draw the whole schematic now; mark the power stage provisional in
the title block and here; list exactly what M1/M2a can change.

**What M1 / M2a can still change.** The buck (TPS54202 → MP2459 if the rail is
unregulated or exceeds ~24 V unloaded); the bulk capacitor (220 µF is calculated,
not measured); the EN divider threshold; and whether the backlight is fed from a
5 V intermediate rail (drawn) or a dedicated boost. Nothing downstream of 3.3 V.

---

### 2026-08-22 — 5 V intermediate rail with a 3.3 V LDO, provisionally

**Context.** The backlight needs 2.8–3.2 V at 80 mA (HS20HS072RX datasheet §3.2)
and cannot run from 3.3 V with any control. The bench needs the board to run from
USB when no bus is connected. Both were open items deferred to M2a.

**Options.** (a) Buck to 3.3 V plus a small boost for the backlight, USB VBUS
diode-ORed into the buck input (4.7 V in is above the 4.5 V minimum). (b) Buck to
5 V, ME6211C33 LDO to 3.3 V, backlight from 5 V through a resistor and a
PWM-driven N-MOSFET, USB VBUS diode-ORed straight into the 5 V rail.

**Decision.** (b), provisionally. The schematic is drawn this way.

**Reasoning.** One regulator fewer to qualify (the LDO is a $0.05 SOT-23-5 part
with 60 µA quiescent, ME6211C33M5G-N, C82942), USB bench power becomes trivial,
and the backlight gets a real current path. The cost is efficiency on the logic
rail: the LDO drops 1.7 V, which at a 25 mA Wi-Fi-idle average is about 42 mW,
or ~2 mA from the 21 V bus. The boost option's own quiescent current is of the
same order. M2a decides whether that 2 mA matters; if the rail is starved, the
design flips to (a) and the change is contained in the power region.

**Consequences.** Second regulator on the board. LDO dissipation at the Wi-Fi
transmit peak (≈350 mA × 1.35 V ≈ 0.47 W) is momentary; at a sustained OTA
download (~150 mA) it is ~0.2 W in SOT-23-5 — measured in bring-up, not assumed.

---

### 2026-08-22 — Buck details: 22 µH, 100k/13.3k feedback, 100k/15k EN divider

- **VFB = 0.596 V** (TPS54202 datasheet SLVSDJ8, §6.5). 100 kΩ / 13.3 kΩ gives
  5.08 V and is the pair TI uses in its own 5 V design example (§8.2).
- **22 µH, not the 10 µH in the candidate list.** Inductor ripple
  ΔI = Vout·(1−D)/(L·f) at 21 V in, 5 V out, 500 kHz: 10 µH → 0.76 A p-p, larger
  than the load; 22 µH → 0.35 A. Same FNR6045S family, FNR6045S220MT, C168080,
  2.2 A saturation, 116 mΩ.
- **EN must not be tied to the input.** EN absolute maximum is 7 V (§5.1); the
  rail is 21 V. 100 kΩ / 15 kΩ: 2.9 V at 22 V in, 3.7 V at the 28 V operating
  maximum, and the converter starts at ≈ 9.3 V (1.21 V rising threshold, §6.5).
  A 9 V start keeps a sagging bus from brown-out cycling the radio.

---

### 2026-08-22 — ESP32-C3 GPIO map, decided by wire order

**Context.** On the WROOM-02 symbol fourteen I/Os sit on the left edge at 2.54 mm
pitch and two on the right. If functions are not grouped by physical adjacency
the schematic fills with crossings, and the same is true of the PCB.

| GPIO | Function | Note |
|---|---|---|
| IO0 | TFT_MOSI (SDA) | |
| IO1 | TFT_SCK (SCL) | |
| IO2 | TFT_DC (RS) | strapping; 10 kΩ pull-up — DC is don't-care between transfers, so the pull-up costs nothing |
| IO3 | TFT_CS | |
| IO4 | BTN_ADC | **ADC1_CH4**. ADC1 is GPIO0–4 only; GPIO5 is ADC2_CH0 and ADC2 is unusable while Wi-Fi runs. A first draft had the ladder on IO5 and was caught in review |
| IO5 | LED_PWR | |
| IO6 | RS485_RX (RO) | |
| IO7 | RS485_DE (DE and ~RE tied) | 10 kΩ pull-down keeps the driver off through reset |
| IO8 | RS485_TX (DI) | strapping; 10 kΩ pull-up, and UART TX idles high anyway |
| IO9 | BOOT test pad | strapping, internal weak pull-up (datasheet table 4-1) |
| IO10 | LED_FAULT | |
| IO18 / IO19 | USB D− / D+ | native USB-Serial-JTAG |
| IO20 | LED_BUS | right side; flickers with the ROM boot log, which is fine for a bus LED |
| IO21 | TFT_BL_PWM | right side; input at reset → backlight off until firmware says otherwise |

**Strapping, from the module datasheet §4.1.** GPIO2 must read 1 at reset
("recommended to pull this pin up due to glitches"); GPIO8 must read 1 for the
joint download boot that the first USB flash relies on; GPIO9 has an internal
weak pull-up. Hence the pull-ups on IO2 and IO8 and the test pad on IO9.

**Button ladder.** 10 kΩ pull-up, switches to ground through 0 / 1.5 k / 3.3 k /
6.8 kΩ: 0, 0.43, 0.82, 1.34 V pressed, 3.3 V idle. 100 nF on the node. The
order of the four display lines (IO0–IO3) and the button line (IO4) matches the
pin order on the FPC connector, which is why the schematic has no crossings there;
the ADC constraint above is what fixed the button on IO4 rather than IO0.

---

### 2026-08-22 — Display tail is 12-pin: FH12-12S-0.5SH replaces the 30-pin connector

**Context.** The candidate list carried a 30-pin FPC connector. The display
datasheet (HS20HS072RX, §6) lists **12 pins**: GND, CS, RS, SCL, SDA, RST, NC,
IOVCC, VCC, LED A, LED K, GND.

**Decision.** Hirose FH12-12S-0.5SH (C88360, $0.44, 5 077 in stock) — footprint
and 3D model ship with KiCad. Value field on J3 is the display part number.

**Open.** FH12 is bottom-contact. The tail's contact side is read from the
display's mechanical drawing before the order; if it is top-contact, the swap is
to a double-sided part and a library addition.

**Reset.** RST has a 10 kΩ / 1 µF RC from 3.3 V, no GPIO spent.

---

### 2026-08-22 — Symbol mirroring and a tool convention that was wrong

J1 and U4 are mirrored (`mirror y`) so that field wiring enters from the left
and bus pins face the terminal. The MCP's pin-position tool reports rotation 90
mirrored relative to KiCad; the netlist, not the tool, is what was checked.
Details in `layout-notes.md`.

---

### 2026-08-22 — Board floor plan: UI left, I/O right, antenna over the top edge

**Context.** Placement had to start before the enclosure exists (Miro's order:
parts → layout → enclosure), so the board itself fixes what the enclosure must
respect: wire entry, display position, button row, antenna clearance.

**Options.** Antenna flush with the edge on a copper-free area, or over the edge
as Espressif prefers; terminal block on the bottom edge under the buttons or on
the right edge; display glass resting on the board or held only by the front
panel.

**Decision.** 104 × 66 mm, single-sided assembly. Display glass area reserved on
the top side (component-free, the glass may rest on the board), four buttons
centred under it, LEDs beside it, FPC connector on the glass's short edge. The
module sits top-right with its antenna 6 mm over the top edge. Terminal block and
USB-C on the right edge, wire entry and plug from the right. Buck in the
bottom-right corner, RS-485 front end between terminal and module.

**Reasoning.** The Espressif hardware design guide marks the over-the-edge
antenna as the strongly recommended position and asks for ≥ 15 mm to metal in
the housing; putting the module in a corner with the display on the far side
keeps the glass's metal frame and every connector ≥ 20 mm away. One edge for all
field wiring keeps the enclosure's cable path to one wall and leaves the front
free for the user interface only. Single-sided assembly is the cheaper PCBWay
order and the board has the area for it; the original panel was 90 × 110 mm, so
104 × 66 mm is no regression in size.

**Consequences.** The enclosure brief inherits: display window centred on
(33.9, 26.1) from the board's top-left corner, button centres at y = 52, LED
column at x = 63.8, cable entry on the right wall, ≥ 15 mm of non-metal around
the antenna above the top edge, and a panel gap beside U1 for assembly. If the
display tail turns out to exit another edge, J3 moves and nothing else does.

---

### 2026-08-22 — Display tail contacts face the viewer: tail folds over J3, J3 entry faces away from the glass

**Context.** The FH12-12S-0.5SH is bottom-contact. Which face of the HS20HS072RX
tail carries the contacts decides whether the tail goes straight into a connector
facing the glass or folds over a connector facing away from it. The drawing
suggested the viewer side; a third-party model said the back.

**Evidence.** LCSC's two part photographs (C5329582 front and back): the front
photo shows the gold contact fingers and the LED test pads on the viewer-side
face of the tail; the back photo shows a black stiffener at the same spot and no
metal. Two independent photos agree with the drawing's front view.

**Decision.** Contacts face the viewer. The tail leaves the glass over J3, rises
over the connector body, folds 180° and enters J3 from the side away from the
glass. J3 is therefore rotated 180° from the first placement: insertion face
toward +x, 9.5 mm from the glass edge (pads at x = 63.05, centre y = 25.92 so that
connector pin 1 meets tail contact 1 at y = 28.67). Fold arithmetic: tail 20.7,
insertion 3.8, bend radius 0.6 → fold axis 12.26 mm from the glass edge; entry
distances between 8.2 and 10.8 mm keep the fold in the tongue and clear of the
connector. Both poses are modelled in mironet-hw-lib; the board carries the
`_TailFolded` variant so the enclosure fit check sees the loop (outer extent
12.3 mm from the glass edge, top of the loop at z ≈ 1.7 mm).

**Consequences.** Nothing may stand taller than about 1.2 mm under the tail
root between the glass and J3, and the R10/C9/R21 column moved 2 mm right to sit
beside the loop rather than under it. The straight-pose footprint stays in the
library for incoming inspection; it is not what goes on a board with an FH12.

---

### 2026-08-22 — Straight tail into a top-contact FH12A; J3 mirrored in the schematic

**Supersedes the fold decision above.** The fold works, but with the FH12's 2.0 mm
body the loop rises above the glass plane and every unit needs a manual fold.
Miro's call: run the tail straight and move the connector east; the glass stays.

**Evidence.** Hirose FH12 catalogue p. 10: one land/metal-mask table serves both the
bottom-contact FH12 and the top-contact FH12A (12 P: A 5.5, B 11.1, C 7.5), so
KiCad's `Hirose_FH12-12S-0.5SH` footprint and model serve the FH12A unchanged.
JLCPCB C596811 FH12A-12S-0.5SH(55), $1.65, 366 in stock (FH12 was $0.44).
Hirose's FPC spec for the family (0.3 ± 0.03 thick at the contacts, stiffener
≥ 0.188, 3.5 mm contacts, 6.5 mm wide for 12 P) matches the HS20HS072RX tail.

**Decision.** J3 = FH12A-12S-0.5SH(55), entry face toward the glass, 16.9 mm from
the glass edge (footprint at (72.3, 25.92) rot 270, pads at x 74.15), tail
straight with its contacts up. DS1 carries the straight-tail model.

**Pin order — decided by coordinates, not by numbering.** Tail contact 1 (15.28 mm
from the glass left edge in the portrait front view) sits at board y 28.67 and
contact 12 at 23.17 (DS1 rot 90). Facing the glass, the footprint's pad 1 is at
y 23.17 and pad 12 at 28.67. A straight insertion therefore puts tail contact k
on pad 13−k; the earlier fold restored k↔k because the fold flips the tail. The
schematic J3 symbol is mirrored (`mirror x`, moved 2.54 mm so every wire meets
the pin that now sits where the old one was): J3 pin 1 = display 12 (GND), 2 =
LEDK, 3 = LEDA, 4 = VCC, 5 = IOVCC, 6 = NC, 7 = RST, 8 = MOSI, 9 = SCK, 10 = DC,
11 = CS, 12 = GND. Verified from the netlist pin-by-pin and by coordinates on the
board: pad 11 (y 28.17) carries TFT_CS and meets contact 2 (CS) at y 28.17.

**Consequences.** +$1.21 per board on the connector, stock 366 to re-check at the
pre-order gate (Hirose is also at Digi-Key/Mouser/Farnell). The tail lies at
z ≈ 1.2 → 0.5 mm over x 60–77, y 23–29 (root 20.6 wide over x 60–70): nothing
taller than ~0.8 mm there — R10/C9/R21 moved to x 78.5, Q1 and R11 down. A wrong
mirror would put 5 V (LEDA) on the display's RS pin, so the mapping is re-checked
against a sample with an ohmmeter before the backlight is powered. Verify
FH12A's "No. 1" marking against the FH12 footprint's pad 1 on the Hirose drawing
before ordering — the mirror above does not depend on it, but the silkscreen
pin-1 mark on the board should match the part.

---

### 2026-08-22 — Power stage no longer provisional: TPS54202 stays, rail measured

**Context.** The buck, bulk capacitor and EN divider were drawn provisionally on
2026-08-22 pending M1/M2a, with the stated trigger "TPS54202 → MP2459 if the rail
is unregulated or exceeds ~24 V unloaded".

**Evidence.** M2a: the factory panel draws 450 mA continuous, 700 mA momentary at
~22 V (`docs/measurements/2026-08-22-panel-current.md`). M1 no-load row: 22.8 V
with the panel disconnected (`docs/measurements/2026-08-22-rail-voltage-no-load.md`).
Instrument and mains voltage not yet recorded; the margins below do not depend
on them.

**Decision.** TPS54202 stays; 22 µH, 100k/13.3k feedback, 100k/15k EN divider
unchanged. The 5 V intermediate rail with the ME6211 LDO stays: the board's 3.3 V
load is unchanged and the rail-side budget (0.1–0.2 A against a demonstrated
0.45–0.7 A) is no longer a constraint. Bulk 220 µF stays as calculated; the rail
is stiff enough that it is now sized for the Wi-Fi burst, not for the source.

**Reasoning.** 22.8 V unloaded × 1.10 for mains at +10 % ≈ 25 V, 3 V under the
28 V operating maximum (SLVSDJ8 §6.3) and the EN divider then sits at 3.3 V
against a 7 V absolute maximum. The rail rose only 0.8 V when ~10 W came off it,
so it is not the soft 14 VA winding the documents describe — which is recorded in
the research notes, not resolved, and not needed.

**Consequences.** The "provisional" mark comes off the title block at the next
schematic edit. Routing of the power corner is unblocked. Still open before
ordering: full-load rail reading (fan 8, heating) for the lower end of the input
range, and the instrument name for the datasheet.

---

### 2026-08-23 — Signal nets autorouted with Freerouting, power routed by hand

**Context.** After the power stage, RS-485 front end and USB-C were routed by
hand (file route, coordinates from the board), 44 connections in the MCU cluster
and display fan-out remained. Blind coordinate routing there was slow and kept
colliding with the 3V3 trunk and the 0.5 mm-pitch fan-outs.

**Decision.** Keep the hand routing for everything that carries current or
EMC intent (buck hot loop, 5 V, 3V3 trunk, RS-485 pair, USB), and let
Freerouting route the remaining 24 low-speed signal nets with the hand copper
as fixed obstacles. Merge only those nets' tracks and vias.

**Reasoning.** The signal nets are 9600-baud UART, SPI to a display, buttons and
LEDs: topology does not matter, clearance and connectivity do, and kicad-cli DRC
is the authority on both. Routing them by hand would have cost hours for no
electrical benefit. The power corner is where the routing is a design choice, and
it stays hand-made and documented.

**Consequences.** Java (OpenJDK via Homebrew) and `freerouting.jar` join the
toolchain; the method lives in the workspace. Autorouted tracks run under the
module's pin field and along the right margin — legal by DRC, to be reviewed by
eye before ordering. `routes.json` is no longer the whole truth; the board file is.

---

### 2026-08-23 — Rev A parts locked: every schematic line carries Manufacturer, MPN and LCSC

**Context.** Only J3 had sourcing fields; 56 lines had value and footprint only, and
the DNP parts R5/R6/R7 were marked in the value text, not the attribute. The order
gate (`/pcba-order`) reads the schematic, so the schematic has to be the BOM.

**Evidence.** Every code was checked against the JLCPCB catalogue on 2026-08-23
(MCP `lib_get_component_details` / jlcsearch): MPN, package, stock, Basic/Extended.
The list is `hardware/docs/parts-revA.csv` (the file the fields were written from).
Where the MCP detail lookup disagreed with the catalogue list (C25804 reported
stock 0 / not Basic; the list shows 37 M / Basic) the list was taken and the
discrepancy noted — re-check at the pre-order gate as the rules require anyway.

**Decisions.**
- Passives: UNI-ROYAL 0603 1 % resistors, Basic, except R4 13.3 kΩ (C25952,
  Extended — TI's 5.08 V feedback value kept rather than rounding to a Basic 13 kΩ,
  which would give 5.18 V and 81 mA in the backlight) and R11 27 Ω 1206
  (C17946, Extended, 0.25 W for the 0.17 W backlight dissipation). Ceramics:
  Yageo 100 nF 50 V X7R (C14663), Samsung 10 µF/10 V (C19702), 1 µF/50 V
  (C15849), 2.2 µF/50 V 0805 (C377773), 22 µF/25 V 0805 (C45783) — all Basic.
  Bulk C1: Nichicon UCD1V221MNL1GS, 220 µF/35 V, 8 × 10 mm, 300 mA ripple
  (C136294) — chosen over cheaper no-name SMD cans for the datasheet and the
  second source; the 35 V rating is 71 % of the 25 V worst-case rail.
- Semiconductors and modules as in the research notes: U1 C2934560, U2 C191884,
  U3 ME6211 C82942, U4 THVD1400 C3235232, D1/D3 SS34 C8678, D2 PSM712-LF-T7
  C32677, Q1 AO3400A C20917, F1/F2 JK-mSMD010-60 C1884489, J2 TYPE-C-31-M-12
  C165948, SW1–4 PTS645SM43SMTR92LFS C221880. **L1 is the 22 µH FNR6045S220MT
  (C168080, 2.2 A sat, 116 mΩ)** — the schematic's 22 µH, not the 10 µH the
  candidates table still lists.
- **Indicator LEDs** (new decision): the LED sits behind 1 kΩ from a 3.3 V GPIO,
  so an InGaN "green" (Vf 2.6–3.6 V, e.g. the 19-217/GHC C2986059 in the research
  notes) would pass 0–0.3 mA and not light. PWR = yellow-green XL-1608SYGC-06
  (575 nm, Vf 2.2 V, C965805); BUS = yellow NCD0603Y1 (595 nm, Vf 1.6–2.6 V,
  C84268); FAULT = red KT-0603R (Vf 1.8–2.4 V, C2286, Basic). Drive is 0.9–1.5 mA;
  brightness in the machine room is judged at bring-up and R20/R26/R27 can go
  down to 470 Ω without a layout change.
- **J1 = Dorabo DB128V-5.08-5P-GN-S (C2927513, 19 115 in stock, $0.56).** Screw
  terminal, side wire entry, 5.08 mm pitch, 2.5 mm² / 22–12 AWG, M2.5 screws.
  No Phoenix MKDS 1,5/5 exists in the JLCPCB catalogue (only 2-pole). The
  datasheet (Dorabo customer drawing DB128V-5.08-XXP-C-S, 2022-10-27) gives pin
  0.80 × 1.00 mm and a recommended PCB hole of Ø1.60 mm; the MKDS footprint on the
  board had Ø1.3 mm, smaller than the pin's 1.28 mm diagonal. **J1's five pads now
  drill Ø1.6 mm (pad Ø2.6 kept, 0.5 mm annular ring)** — a board-instance change
  that DRC reports as `lib_footprint_mismatch` on J1, accepted. Body 10.2 mm deep
  vs the footprint's 9.92: the wire-entry face sits 0.12 mm inside the board edge
  and the back 0.4 mm further inboard than the MKDS outline; nothing is within
  0.4 mm behind J1.

**Consequences.** `kicad-cli sch export bom` now yields 57 lines with MPN and LCSC,
R5–R7 carry `dnp yes`; the board footprints carry the same fields and the DNP flag
(file route, what F8 would have done), schematic parity is clean. Extended parts
(feeder fee each): U1, U2, U3, U4, R4, R11, F1/F2, L1, J1, J2, J3, SW1–4, D4, D6
and C1 — 16 types. Re-check stock at the pre-order gate: SW1–4 (1 421), U1 (3 702),
J3 (366 on 2026-08-22).

### 2026-08-24 — Enclosure: two-part shell, membrane buttons, single-axis stack

**Context.** The board (rev A, routed) needed its first enclosure so the project
can show a complete device, the simulator can render the case, and Fusion has
real geometry to start from. The panel lives under the machine in a technical
room: no size constraint, but dust from the adjacent blower argued against
openings.

**Options.** One deep tray with a flat lid, or a shallow base with a shaped
cover; buttons as holes with separate caps, or printed membranes over the
tactile switches; USB-C exposed through the wall or kept inside.

**Decision.** Shallow base + cover with an L-shaped raised section over the two
tall parts (C1 10.5 mm, J1 13.8 mm — heights read from the STEP models, not
datasheets alone). Printed membranes (0.6 mm, Ø4 nub, 0.3 mm gap) over the
PTS645 switches — the 1.6 N variant was chosen for exactly this. USB-C stays
inside (recovery = open the cover; OTA rollback is the primary path). Cover
screws M3×8 countersunk into heat-set inserts; the top-right post sits on the
right wall at y=18 because a corner post would put a steel screw 13.6 mm from
the antenna (≥15 mm rule). 8 mm antenna bay past the top edge, 14 mm wiring bay
on the right with a 7 mm cable slot and zip-tie anchors.

**Reasoning.** Every clearance is computed by `mechanical/draft/enclosure.py`
and checked by a boolean interference test against the populated pcb.step
(0 collisions; table in the script output). The single-axis stack (base → board
→ cover → screws) keeps assembly and the exploded documentation view trivial.

**Consequences.** Fusion takes over from the STEPs; the draft scripts stay as
the dimensional record. Membrane stiffness (0.6 mm PETG over Ø11) is untested —
first print decides. The blister roof needs supports when the cover prints
face-down. The screw model uses nominal DIN 965 numbers; verify against the
actual fastener before drawings.

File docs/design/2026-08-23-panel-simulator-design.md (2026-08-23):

# Panel UI core and browser simulator — design

Date 2026-08-23 · Status: approved in discussion, awaiting review of this text ·
Applies to firmware rev 0.x on hardware rev A

## 1. Purpose

The device replaces the original Vallox DIGIT SE panel, so it carries the panel's
user interface: a 320 × 240 display, four buttons, three indicator LEDs, and
every setting the original panel could reach. This design covers three things
that are built together because they share one core:

1. **`panel_ui`** — the menu engine, state machine, renderer and texts that run
   on the device.
2. **`vallox_machine`** — an emulator of the machine side of the RS-485 bus,
   register map plus a coarse thermal model, used by host tests and by the
   simulator.
3. **The browser simulator** — the same `panel_ui` and `vallox_machine` compiled
   to WebAssembly, drawn onto the board's 3D model (three.js), with a side panel
   to drive the machine. Published on GitHub Pages, linked from the README, so a
   reader can use the device before ordering a board.

The simulator is not a demo written beside the firmware; it is the firmware's
UI core in another host. There is one copy of the UI logic.

## 2. Decisions taken

| Question | Decision | Why |
|---|---|---|
| Scope of the menu | **Option C:** basic functions now (fan speed, four temperatures, heating setpoint, boost, faults, service reminder); the menu engine is table-driven so every further setting is one table row | No rewrite when the installer menu arrives after the M3 capture confirms registers |
| Drawing layer | **Own narrow renderer** + fonts pre-rendered at build time from a TTF (Inter, SIL OFL) into 4-bit antialiased bitmaps, three sizes | Typography and disciplined layout make the look; LVGL would cost a large dependency and a recognisable style; a runtime font engine is not needed at 320 × 240 |
| Browser realism | **3D from the start, bare PCB** from KiCad's GLB export; the enclosure becomes a show/hide toggle when its STEP exists | The board model with display, buttons and LEDs already exists; the enclosure does not |
| Machine model | **Coarse physics** (option B): temperatures follow fan speed, outdoor temperature, heat-recovery efficiency and the heater setpoint with a time constant; faults injectable | The demo convinces when the machine reacts; it is also the test bench for UI behaviour under changing values |
| Display language | **English and Finnish**, selectable in settings; all texts through one key table from day one | Cheap now, painful later; shows localisation was considered |
| Host boundary | One C core, thin HAL as plain C functions linked per host; four hosts: ESP-IDF, ESPHome, host test runner, Emscripten | Deterministic tick-based core behaves identically everywhere; no runtime function pointers needed on the MCU |
| Where the machine model lives | In C, inside the same WASM module as the UI | The host tests need it; two models (C + JS) would drift |

Rejected: a JavaScript re-implementation of the UI ("look-alike demo") — the
duplicate logic `firmware.md` forbids; LVGL; putting the machine model in JS.

## 3. Architecture

```
firmware/components/
├── vallox_protocol/   exists   frames, parser, value encodings, bus survey
├── vallox_machine/    new      machine emulator: register map + tick physics + fault injection
├── panel_ui/          new      menu engine, state machine, renderer, fonts, texts (en/fi), vlx_client
└── panel_hal/         new      header only: the contract every host implements

hosts
├── firmware/main/             ESP-IDF: UART + DE, ST7789 SPI, ADC buttons, NVS, Wi-Fi later
├── esphome/components/...     ESPHome wrapper (existing, grows)
├── firmware/test/host/        Unity tests, PNG writer, memory bus between UI and machine
└── simulator/                 Emscripten build of ui + machine, three.js view, side panel, Pages deploy
```

The core never touches a UART, a clock, a display driver or storage. It is
driven by `panel_ui_tick()` at ~50 Hz from whichever host owns time. No threads,
no callbacks inside the core.

### 3.1 `panel_hal.h`

Plain C functions, one implementation per host, resolved at link time:

| Function | Contract |
|---|---|
| `void hal_display_flush(uint16_t x, uint16_t y, uint16_t w, uint16_t h, const uint16_t *rgb565)` | Copy a rectangle to the panel (ST7789 window write / canvas texture sub-update) |
| `uint16_t hal_buttons_read_mv(void)` | Button-ladder voltage in millivolts. The core maps it to a button; the thresholds are core code and are tested |
| `void hal_leds_set(bool pwr, bool bus, bool fault)` | Three indicator LEDs |
| `void hal_backlight_set(uint8_t level)` | 0–255 PWM duty |
| `size_t hal_bus_write(const uint8_t *buf, size_t len)` / `size_t hal_bus_read(uint8_t *buf, size_t max)` | RS-485 bytes. Driver-enable timing belongs to the host |
| `uint32_t hal_time_ms(void)` | Monotonic milliseconds |
| `bool hal_store_get(const char *key, void *buf, size_t len)` / `bool hal_store_put(...)` | Settings: NVS on the device, `localStorage` in the browser, a RAM table in tests |

Expected ladder levels from the rev A schematic, simulated 2026-08-23
(`docs/measurements/2026-08-23-spice-rev-a.md`): none 3300, SW1 0, SW2 430, SW3
819, SW4 1336 mV. Thresholds sit at the midpoints; the bring-up measurement of
the real levels replaces the table, not the code.

### 3.2 `panel_ui`

**Screen.** Three zones: a top bar (page title, bus state, fault icon), content,
and a bottom bar showing the four buttons' current meaning (`− + OK ←` change by
page) drawn directly above the physical buttons (13 mm pitch under the glass).

**Pages are data:**

```c
typedef struct {
    const char  *title_key;            // text-table key
    page_kind_t  kind;                 // DASHBOARD | LIST | EDITOR | INFO
    const item_t *items; uint8_t n;    // LIST rows -> sub-page or editor
    uint8_t      reg; value_enc_t enc; // EDITOR: register + encoding (fan 1–8, °C, %, min, bit)
    int16_t      min, max, step;
} page_t;
```

A new setting is one `page_t`/`item_t` row. Value encodings come from
`vallox_protocol` (NTC table, speed bits), so the editor knows nothing about
Vallox. The dashboard is the only hand-drawn view: fan speed large, four
temperatures, heater/bypass state, boost minutes left.

**State machine.** A page stack (depth ≤ 6); button events `PRESS / REPEAT /
LONG` with debounce and auto-repeat in the core; dashboard timeout 60 s; dim
after 5 min to 10 % backlight, wake on any button; `←` held at power-up restores
factory settings (decided earlier, `decisions.md`).

**Data flow.** The UI does not write registers directly. `vlx_client` (part of
`panel_ui`, on top of `vallox_protocol`) owns the poll sequence, the write
acknowledge byte, the 10 ms response window and a **shadow register map with
timestamps**. Views draw from the shadow; a value older than 30 s is drawn
dimmed — the UI is honest when the bus is quiet.

**Renderer.** RGB565 framebuffer, 150 kB (ESP32-C3 has 400 kB; a band buffer is
the fallback if RAM gets tight), dirty-rectangle list, primitives: fill, line,
rounded box, text, icon. Fonts from `tools/fontgen.py`: TTF → 4-bit antialiased
glyphs at 12/18/36 px, ASCII + `äöåÄÖÅ` + `°`, emitted as `.c` tables. One theme
struct (colours, spacing); dark by default because the panel hangs under the
machine in a plant room. Texts `texts_en.c` / `texts_fi.c` over one key enum; a
build-time check fails if the Finnish table lacks a key.

### 3.3 `vallox_machine`

**Interface.** `vlx_machine_init(&m, profile)`, `vlx_machine_feed(&m, bytes, n)`,
`vlx_machine_tick(&m, now_ms, out, &out_len)`, `vlx_machine_fault(&m, code)`.
It is itself a bus device at `0x11` using the same parser as the UI: all traffic
is genuine six-byte frames through a memory buffer, in tests and in the browser.

**Registers.** The whole map from `vallox_protocol.h` as a table: address,
read/write, default, encoding, and the confidence class from
`docs/research/protocol.md` (`manufacturer` / `implementations` / `assumed`). A
register the documents do not describe gets **no answer** — the UI sees a
timeout, not an invented value. Writes update the register and return the
acknowledge byte; polls are answered within a configurable delay (0 / 10 / 200
ms / never) so the UI's timeout path is testable. Broadcast set `2B 2C 35 34 32
33` every 12 s, the start-up burst, `SUSPEND/RESUME` around the CO₂ exchange.

**Physics.** Parameters: `t_outdoor` (from the side panel), `t_indoor` = 21 °C,
heat-recovery efficiency η = 0.6, heater setpoint and fan speed from registers.
Per tick: `t_extract → t_indoor` with a time constant; `t_supply = t_outdoor +
η·(t_extract − t_outdoor)`, raised to the setpoint when the heater bit is on;
`t_exhaust` likewise; time constant ∝ 1/fan_speed and scaled by `time_scale`
(1×/10×/60×) for the demo. Results go through the NTC table back to raw bytes
so the UI's decoding is exercised. Frost protection: `t_exhaust` under the
register threshold → supply-fan-stop bit and a fault; service reminder from the
month counter. Fault injection sets register 0x36 and the status bit until the
UI acknowledges.

**Not modelled:** CO₂/RH sensors (`fitted = 0`), the LON module, programme 2's
week clock — listed in the README as gaps, not guessed.

**Source of truth.** The model is exactly as right as `protocol.md`. A
discrepancy found in the M3 capture is corrected in the protocol document
first, then in the model and the UI in the same PR.

### 3.4 Browser simulator (`simulator/`)

**Build.** Emscripten compiles `vallox_protocol + vallox_machine + panel_ui +
panel_hal(web)` into one `panel.wasm` (`-O2`, no exceptions/iostream, ~100–200
kB). JS: three.js plus small vanilla code, bundled with Vite; no UI framework.
Output is a static `dist/`, deployed to GitHub Pages by `simulator.yml` from
`main` only. Licences: three.js MIT, Inter OFL, own code MIT — within the
existing `LICENSE.md` split.

**Scene.**
1. *Board.* `kicad-cli pcb export glb --subst-models --include-tracks
   --include-zones` of rev A, generated in CI, not committed. PBR materials as
   exported, one small HDRI environment, soft contact shadow. OrbitControls,
   default ¾ view, a "front view" button; touch works.
2. *Live display.* A plane at the display's active area (40.8 × 30.6 mm, position
   known from the library model) carrying a `DataTexture`; `hal_display_flush`
   writes RGB565 into shared memory and JS updates only the dirty rectangle
   (`texSubImage2D`). A thin translucent glass plane above it for the reflection.
   Backlight level → texture brightness.
3. *Buttons and LEDs.* Raycast onto hit boxes placed from the board coordinates
   (SW1–4 at x = 14.5/27.5/40.5/53.5, y = 52 mm — GLB node names are not relied
   on); keys `← → Enter Backspace` map to the same; a pressed button sinks 0.3 mm.
   LEDs are small emissive planes at D4/D6/D5 (yellow-green / yellow / red), light
   bloom. **Enclosure checkbox:** reserved; a second GLB in the same scene once
   the STEP exists; the core does not change.

**Side panel** (right, collapses below on phones): machine state (fan speed, four
temperatures, heater/bypass/frost bits), controls (outdoor temperature −25…+30
°C, time scale, response delay, language), fault injection, and a **bus log** in
hex, one frame per line (sender → receiver, register, value, direction). No
MQTT/Home Assistant mock in the first release.

**Realism, honestly.** GLB materials are KiCad's defaults, which are right for
rev A (green mask, HASL, white silk); the photographic quality comes from
lighting and the glass reflection, not from swapping the model.

## 4. Testing and CI

**Host tests (Unity, `firmware/test/host/`):** ladder thresholds incl. ±50 mV
edges; debounce/repeat/long as tick sequences; page-stack navigation; editor
limits and steps; timeouts; text-table key parity (build-time). **Golden images:**
scenarios (dashboard, list, editor, fault, dimmed) run as tick sequences →
RGB565 → PNG in `test/host/golden/`, compared pixel-exact; a deliberate look
change updates the golden in the same PR and the diff is visible in review.
`vallox_machine`: poll answers and acknowledges as real frames, broadcast timing,
physics direction and settling (not exact numbers — those are parameters),
fault injection, `assumed` registers behaving as documented. **End to end on the
host:** UI + machine over the memory bus — "press + three times → speed 4 on the
dashboard and register 0x29 reads 0x0F".

**Browser:** Emscripten toolchain in CI (cached), Vite build, one Playwright smoke
test (page loads, WASM starts, display texture non-empty, a click changes the
view). No visual 3D regression test — rendering varies by GPU; golden images
live in the deterministic host test.

**Workflows:** `firmware.yml` gains the new host tests; new `simulator.yml`: GLB
export with kicad-cli (same container as `hardware.yml`), Emscripten + Vite,
Playwright smoke, Pages deploy from `main`. README badge. CI green is not a
measurement: the README says the simulator runs a *simulated* machine and the
protocol is unverified until M3.

## 5. Staging

| # | Milestone | Done when |
|---|---|---|
| **S1** | `panel_hal.h` + `vallox_machine` + host runner with the memory bus | Machine answers polls and broadcasts in tests; physics moves the right way; e2e "UI stub reads the speed" passes. No UI yet |
| **S2** | `panel_ui`: renderer + fontgen + texts + dashboard + list/editor engine at option-A scope | Golden images for five views; tick-based button handling tested; e2e "press + → register changes" passes; host runner writes a PNG on demand |
| **S3** | `simulator/`: Emscripten build, three.js board from GLB, live display, buttons, LEDs, side panel, bus log, Pages deploy | Smoke test in CI, demo link in the README, enclosure checkbox present (empty) |
| **S4** | ESP-IDF host: ST7789 SPI, ADC buttons, UART + DE, NVS — **after bring-up only** | The same core runs on the board; golden image vs a photograph of the display. ESPHome wrapper grows with it |

S1–S3 are host-only and may proceed before boards exist. S4 waits for bring-up:
that is the `projektit.md` gate and it is a condition here, not a hope.

## 6. Out of scope for the first release

24 h graphs, MQTT/Home Assistant mock in the side panel, enclosure 3D (toggle
reserved), CO₂/RH sensors in the model, programme 2's week clock, an OTA menu
(arrives with the firmware stage), sounds. All listed in the README's "not yet"
section.

## 7. Open items carried into the plan

- Exact active-area origin of the display plane from the library model
  (`mironet-hw-lib`, `LCD_2.0in_HSD_HS20HS072RX`): read from the STEP, not
  assumed.
- Whether a 150 kB full framebuffer fits beside Wi-Fi on the ESP32-C3 is decided
  in S4 with a measured heap figure; the renderer keeps the band-buffer path
  possible (dirty rectangles only).
- Inter licence file and the fontgen tool's pinned TTF version go into
  `firmware/components/panel_ui/fonts/`.

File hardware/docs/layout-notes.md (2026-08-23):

# Layout notes

Chronological, measurement-based log of schematic and PCB work. Written at the end
of every `/kicad-layout` session. Its value is in the numbers and in the dead ends:
"tried X, it did not work because Y" saves the next attempt.

## Template

### YYYY-MM-DD — <subsystem>

- **Baseline.** DRC / ERC violation counts and types before the session.
- **Changes.** What was moved, routed or replaced.
- **Measured.** Values before and after: trace widths, loop areas, clearances, lengths.
- **Did not work.** What was tried and rejected, and why.
- **Result.** DRC / ERC delta against the baseline. Zero new violations, or the reason.
- **Open.** What is left for the next session.

---

### 2026-08-22 — Schematic rev A, first draft (single A3 sheet)

- **Baseline.** Empty sheet. ERC 0 / 0 (nothing to check).
- **Changes.** Whole schematic drawn in one session: 60 components, 35 power
  symbols, 134 wire segments, 52 junctions, 19 net-name labels, 4 no-connect
  flags. Regions left to right: field terminal and power stage (top-left), RS-485
  front end (left-middle), buttons, display connector and USB-C (centre), ESP32-C3
  module with local pull-ups, LEDs and the backlight switch (right). Every signal
  is a continuous wire from pin to pin; labels only name nets.
- **Measured.** Not applicable — no layout. Values that went in from datasheets:
  TPS54202 VFB 0.596 V (SLVSDJ8 §6.5) → 100 kΩ / 13.3 kΩ for 5.08 V, the same
  pair TI uses in its 5 V design example; EN absolute maximum 7 V → divider
  100 kΩ / 15 kΩ, start ≈ 9.3 V at the 1.21 V rising threshold, 2.9 V at 22 V in;
  display backlight Vf 2.8–3.2 V at 80 mA (HS20HS072RX §3.2) → 27 Ω from 5 V,
  67–81 mA; IOVCC 1.65–3.3 V and VCI 2.4–3.3 V → 3.3 V is inside both ranges.
- **Did not work.**
  - `sch_build_circuit` with explicit `wires` produces exactly the drawn wires, but
    it **wipes the title block** — set it again afterwards — and it **does not add
    junctions**. A pin or power-symbol pin that lands on the interior of a wire is
    *not connected* in KiCad without one; ERC showed 40 "pin not connected" errors
    until 52 junctions were written into the file. Wire ends on wire interiors are
    connected without a junction.
  - `sch_get_pin_positions` reports rotation 90 **mirrored relative to KiCad**:
    for SM712 it put the common pin on the left, KiCad put it on the right; for
    D_Schottky it put the cathode at the top, KiCad at the bottom. Rotation 0 and
    180 agree. Consequence: the USB VBUS diode was drawn backwards at rot 90 and had
    to be set to 270; the TVS common wire had to be moved. Symmetric parts (R, C,
    L, fuse, switch) are unaffected. Verified from the netlist, not assumed.
  - No tool mirrors a symbol. J1 (field terminal) and U4 (transceiver) were
    mirrored by adding `(mirror y)` to the symbol instance in the file with KiCad
    closed; pin nets verified from the exported netlist.
  - `sch_render_png` fails on this machine (no libcairo). `kicad-cli sch export pdf`
    is the working route for a visual check.
- **Result.** `kicad-cli sch erc --severity-all`: 0 errors, 1 warning — Q1's
  embedded AO3400A symbol differs from the installed library copy (the MCP writes
  its own copy). Fix in the GUI with *Update Symbols from Library*. Netlist: 47
  nets, the only single-node nets are the four intentional no-connects (U3 NC,
  J3 pin 7, J2 SBU1/SBU2).
- **Open.**
  - Cosmetic: a few value labels overlap near D2/R5/JP1 and near Q1/R13; the
    J1 value sits under the symbol. GUI work.
  - The power stage is provisional until M1/M2a (see decisions).
  - Display tail contact side (top/bottom) is not stated in the datasheet text
    read so far; the FH12 connector is bottom-contact. Check the mechanical
    drawing before ordering, or switch to a double-sided-contact part.
  - DNP parts (R5 termination, R6/R7 bias) are marked in the value field only;
    set the DNP attribute in the GUI so the BOM export honours it.
- **Caught in self-review, same session.** The first draft put the button ladder
  on IO5, which is ADC2_CH0 — unusable with Wi-Fi. Moved to IO4 (ADC1_CH4); the
  display shifted to IO0–IO3 and LED_PWR to IO5. The EN capacitor C13 now shares
  C11's ground point so that the RST capacitor C9 has room. Netlist re-checked
  pin by pin after the change.

### 2026-08-22 — Rev A placement, first pass (no routing)

- **Baseline.** Empty board file (59 bytes, 0 footprints). ERC unchanged from the
  schematic session: 0 errors, 1 cosmetic warning. DRC: nothing to check.
- **Changes.** The board was populated from the schematic netlist with KiCad's
  bundled `pcbnew` Python (KiCad closed), not with the GUI *Update PCB from
  Schematic*: the MCP server had no `pcb_write` tools this session (KiCad was not
  open when it started, so IPC never came up) and the one MCP tool that does a
  file-based transfer is the one the workspace rules forbid. Every footprint
  carries its schematic symbol UUID as `path`, so a later F8 in the GUI should
  reconcile to *no changes* beyond field text — that check is still to be run.
  Outline 104 × 66 mm, 2 mm corner radius, four Ø3.2 mm NPTH at (3.5, 3.5),
  (3.5, 62.5), (100.5, 62.5) and (70, 3.5). All 60 schematic parts placed on the
  top side (single-sided assembly), 4 mounting holes added (H1–H4, no symbol).
  Floor plan, left to right: display glass reserve 51.8 × 36.2 mm at
  (8, 8)–(59.8, 44.2) with the four buttons centred under it (x = 14.5/27.5/40.5/
  53.5, y = 52, 13 mm pitch, symmetric about the glass centre x = 33.9); the three
  LEDs in a column right of the glass (x = 63.8, y = 10/14/18, PWR–BUS–FAULT);
  J3 FPC connector at (67, 26.1) with its FPC entry facing the glass (lip at
  x = 62.6, 2.8 mm from the glass edge); ESP32 module at (92, 7.1), antenna over
  the top edge; USB-C flush with the right edge at y = 26; the 5-pole terminal at
  the right edge with the wire-entry face flush with the edge (pins at x = 99.4,
  y = 35.2…55.5, order from the top M B A − +); RS-485 front end between the
  terminal and the module (fuses 3.5 mm from pins A/B, TVS next to pin M = GND);
  buck in the bottom-right corner (input cap C2 pads 2.5 mm from U2 VIN/GND,
  inductor pad 5.6 mm from the SW pin, bulk C1 beside them, D1 8 mm from J1 +).
  Silkscreen: button legends, LED names, terminal pin names, board name, rev,
  mironet.fi and the repo URL. Reference designators were auto-placed by a script
  (0.8 mm, avoids pads, other courtyards, texts and the edge; rotated where a
  column is dense) — 57/57 resolved, 47 without touching any courtyard.
- **Measured.** Antenna placement follows the Espressif hardware design guide
  (*Positioning a module on a base board*): the 6 mm antenna area hangs over the
  board edge, feed point at the edge, the footprint's keep-out polygon lies
  entirely off-board; the guide's 15 mm metal clearance is an enclosure input and
  is written on Cmts.User next to the module. Nearest metal on the board: the
  USB-C shell at ≥ 20 mm, the top-right mounting hole at (70, 3.5) is 13 mm from
  the module body — use a plastic screw there if in doubt. Module thermal vias
  changed on the board instance from Ø0.2 mm drill (library) to Ø0.3 mm drill /
  Ø0.6 mm pad because the project rules set min hole 0.3 mm; hole-to-hole
  0.48 mm, pad-to-pad 0.18 mm within the same GND paddle.
- **Did not work.**
  - `pcbnew.BOARD.GetDrawings()` is not iterable in KiCad 10.0.2's Python when the
    board has content; the builder therefore always starts from the empty file.
  - `PCB_TEXT.GetBoundingBox()` does not follow `SetTextAngleDegrees(90)` for
    footprint reference fields in this binding — the reference placer computes
    rotated boxes itself.
  - The MCP placement gate FAILs on heuristics that do not hold here: it treats
    U1's off-board antenna keep-out and J1/J2's edge-flush courtyards as "outside
    board" and "overlap", measures decoupling distance to the module *centre*
    (C10 is 3.0 mm from pin 1, 12.7 mm from the centre) and flags J3/JP1 for not
    being at an edge. `kicad-cli pcb drc` is the authority, as the rules say.
- **Result.** `kicad-cli pcb drc --severity-all --schematic-parity`: 0 errors,
  7 warnings — 6 × `silk_edge_clearance` on U1/J1/J2 whose library silkscreen
  crosses the edge by design, 1 × `lib_footprint_mismatch` on U1 (the thermal-via
  change above); schematic parity: 0 mismatches, 4 extra footprints (H1–H4,
  intentional); 138 unconnected items (not routed). The parity run caught two
  things the first build got wrong: footprints written without their library
  nickname (`CP_Elec_8x10.5` instead of `Capacitor_SMD:CP_Elec_8x10.5`) — every
  part was reported as mismatched until the FPID was set — and TP1/TP2/JP1,
  whose library footprints are *excluded from BOM* while the schematic symbols
  were not; the symbols were set `in_bom no` (the right answer for test points and
  a solder jumper) and ERC is unchanged at 0 errors, 1 cosmetic warning. Render and top-view SVG read
  by eye: floor plan as intended. **CI will be red on this branch** until the
  board is routed — the workflow's DRC step uses `--exit-code-violations`, which
  returns 5 for unconnected items as well (verified locally).
- **Open.**
  - Display tail, **checked against the HSD outline drawing the same day**
    (LCSC C5329582 datasheet, sheet "MODULE OUTLINE DIMENSION"): it does leave the
    short edge, centred (contact 1 edge 15.28 ± 0.5 from the glass side, 12 × 0.5
    mm), 20.7 ± 0.5 mm long, flat between glass and backlight. So J3's position
    holds, but a 20.7 mm tail does not go straight into a connector 2.8 mm from
    the glass — it bends, and a fold flips the contact side. Contact side is the
    open question: the drawing reads as viewer-side contacts (stiffener in the
    back view), which with a bottom-contact FH12 means the tail folds over the
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

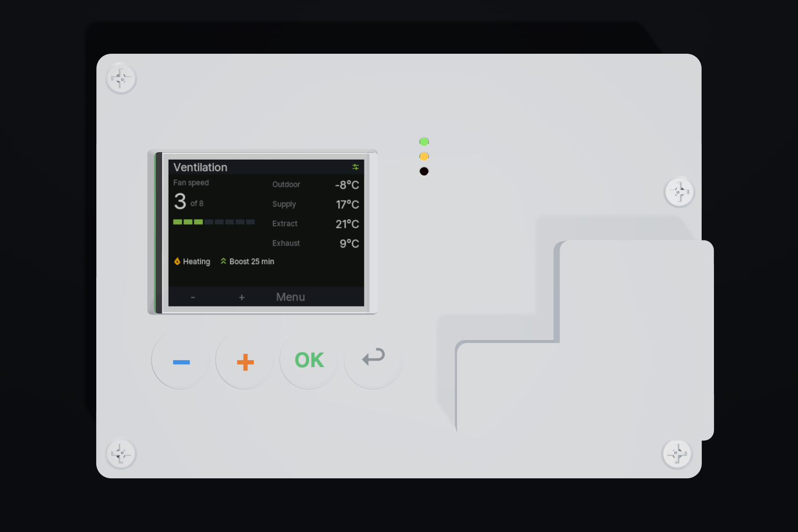
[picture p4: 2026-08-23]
docs/images/enclosure-draft-render-ui-front.png

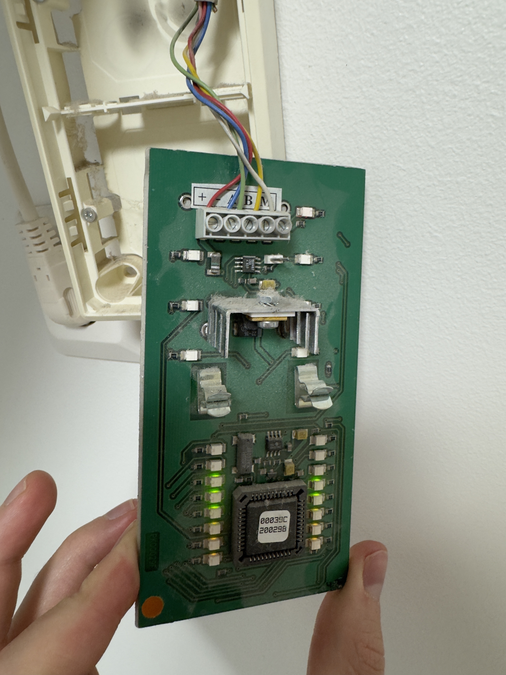
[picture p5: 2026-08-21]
docs/images/panel-pcb-front.jpg

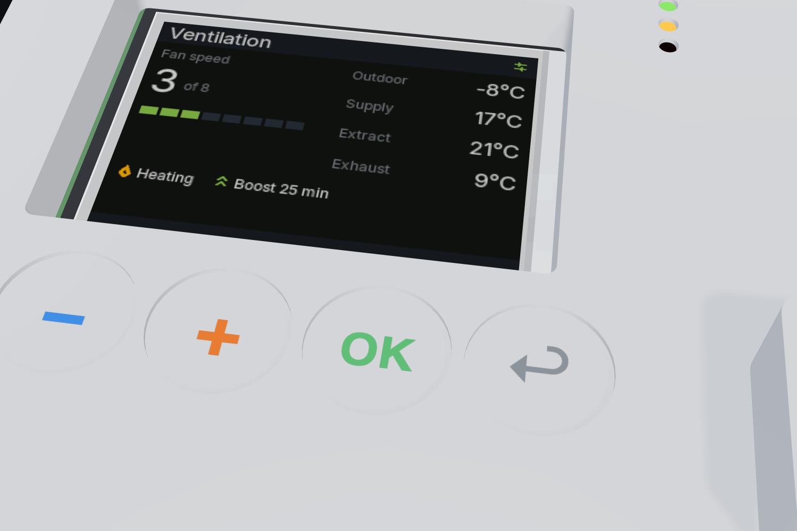
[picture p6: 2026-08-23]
docs/images/enclosure-draft-render-ui-closeup.png

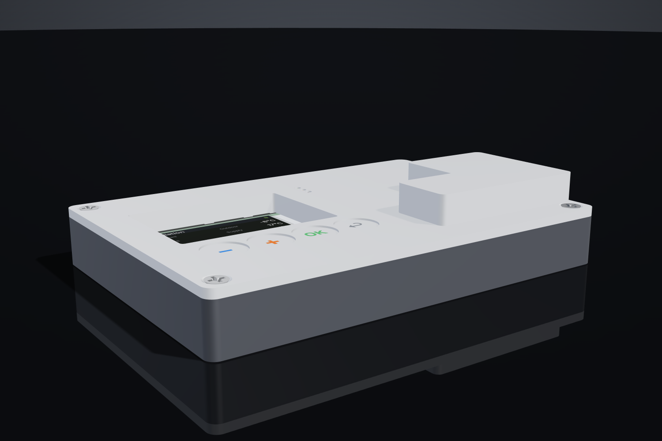
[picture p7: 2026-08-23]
docs/images/enclosure-draft-render-ui-low.png

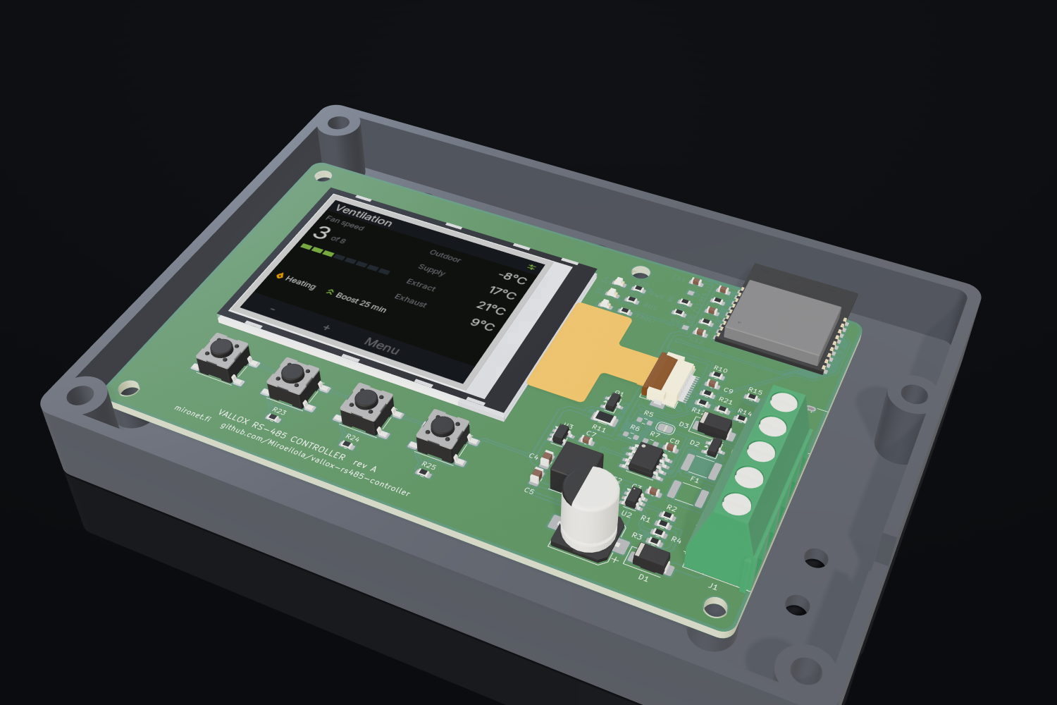
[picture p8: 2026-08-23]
docs/images/enclosure-draft-render-ui-open.png

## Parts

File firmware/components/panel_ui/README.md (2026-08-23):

# panel_ui — the panel's UI core

The menu engine, renderer, fonts, texts, button decoding and bus client that
run on the device, in the host tests and in the browser simulator — one copy,
driven by `panel_ui_tick(now_ms)` at 50 Hz, seeing the world only through
`panel_hal.h`. No ESP-IDF headers, no stdio, no floats, no allocation.

## Screen

320 × 240 RGB565. Top bar (title, bus state, fault icon) 0–23, content 24–207,
bottom bar 208–239 with the four buttons' current meaning drawn above the
physical buttons (`− + OK ←`, left to right; columns at x = 40/120/200/280 for
now — the active-area origin vs the switches is read from the library model in
S3/S4 and shifts those four numbers in `theme.h`).

## Pages are data

`pages.c` holds one `page_t` per page: DASHBOARD, LIST (rows → pages), EDITOR
(register + encoding + min/max/step), INFO. A new setting is one row. Value
encodings come from `vallox_protocol`, so the editor knows nothing about Vallox.

| Page | What |
|---|---|
| Dashboard | fan speed large + 8-segment bar, four temperatures, heater/bypass and boost line, fault banner. `−`/`+` change the speed directly, `OK` opens the menu |
| Menu | Fan speed · Heating setpoint · Status · Settings |
| Fan speed | editor 1…8, saved through the client (0x29 is on the write allow-list) |
| Heating setpoint | editor 10…25 °C, **read-only until verified** — 0xA4 is not on the allow-list, so `+ −` are inert and `OK` leaves |
| Status | fault, service months, bus state, firmware version |
| Settings → Language | English / Suomi, stored under `"lang"` |

Any page: `←` held 1 s → dashboard. 60 s idle → dashboard. 5 min idle → dim to
10 % backlight and hide the button labels; any press wakes and is consumed.
`←` held from power-up for 3 s → factory reset (language), 2 s splash.

## Bus client

`vlx_client` keeps a shadow of the machine's registers with timestamps, polls
one register every 250 ms (list in `vlx_client_default_poll`), takes the
machine's broadcasts, writes with the one-byte acknowledge (3 tries, 50 ms
window), and declares a bus fault after 10 unanswered polls (protocol.md
claim 24). A write is refused before a byte leaves unless
`vlx_register_is_write_allowed()` and `vlx_value_is_valid_for()` agree. Values
older than 30 s are drawn dimmed; unknown values as `--`.

## Fonts and texts

Inter 4.1 (OFL) pre-rendered by `tools/fontgen.py` into 4-bit tables at 12/18/36
px; see `fonts/README.md`. Texts are keys in `texts.h` with `en`/`fi` tables;
a host test fails on a missing key or a glyph the fonts lack.

## Tests

`firmware/test/host/`: `test_panel_fonts_gfx.c`, `test_panel_buttons_texts.c`,
`test_vlx_client.c`, `test_panel_ui.c` (incl. the spec's e2e "press + three
times → speed 4, 0x29 reads 0x0F"), `test_panel_golden.c` with five golden
images in `golden/` (`make golden` regenerates; a look change updates them in
the same PR). `panel_host` renders any state to a PNG from the command line.

## Known gaps

- Fault names exist for the six documented codes; others show `Code N`.
- The acknowledge byte is matched by value within the 50 ms window; a
  broadcast byte equal to it would be mistaken for the ack (re-polled right
  after, so the shadow self-corrects).
- Full-page redraw at ≤ 5 Hz: the dashboard costs 500 `hal_display_flush` calls
  and 85 709 pixels per render (measured on the host, 2026-08-23; text drawing
  was 327 calls / 77 582 px before this change started marking one dirty
  rectangle per string instead of one per glyph — merging narrow per-glyph
  rects had let the pre-existing dirty-list overflow merge coalesce them into
  the same bounding boxes as the surrounding fills, for free; the now-correct
  per-string rects are separate instead, so `gfx_flush`'s one-call-per-scanline-
  per-rectangle design pushes the row total up, not down); flush is one call
  per scanline per dirty rectangle, so the ESP-IDF host should batch rows or
  push the frame whole (S4 decides with a measured heap/SPI figure).
- No scrolling lists (every list fits the screen), no boost/bypass controls,
  no installer menu — option-A scope, the table grows when the M3 capture
  confirms registers.

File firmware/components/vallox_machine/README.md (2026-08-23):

# vallox_machine — a simulated Vallox mainboard

An emulator of the machine side of the RS-485 bus, used by the host tests and
by the browser simulator. It is itself a bus device at 0x11 and speaks only in
the six-byte frames of `vallox_protocol`. **It is exactly as right as
`docs/research/protocol.md`** — nothing here has been checked against a
machine. When the M3 capture disagrees, the protocol document is corrected
first, then this model and the panel in the same PR.

## What it does

| Behaviour | Source | Confidence |
|---|---|---|
| Answers a poll for a known register with its value, to the poller | protocol.md claims 11 (reverse-engineered), 24 (manufacturer) | implementations / manufacturer |
| Answers a write with one byte, the received checksum | claim 25 | manufacturer |
| Ignores writes to read-only or unknown registers, without a reply | no NAK is documented | assumed (silence) |
| Broadcasts `2B 2C 35 34 32 33 2A` to 0x20 every 12 s, 130 ms apart | claim 23 | manufacturer (period) / reverse-engineered (contents) |
| Register map and defaults (status defaults to power on + winter mode / heat recovery) | `vallox_machine_regs.h`, each row with its class | implementations |
| Thermal model: lags toward indoor / recovered / setpoint temperatures | own model, parameters | n/a — a model, not a claim |
| Frost protection: supply fan stop when exhaust drops below the 0xA8 threshold (NTC table, a writable setting), output is bit 3 of 0x08 (IO_MULTI_2); hysteresis from 0xB2 | threshold 0xA8, output 0x08 bit 3, hysteresis 0xB2 | implementations |
| Fault injection; cleared by host or by the panel writing 0 to 0x36 | clearing write | **assumed** |
| Poll-answer delay 0 / 10 / 200 ms / never, counted from the tick that hears the frame; a never-answering machine also withholds the acknowledge | test knob | n/a |

## What it does not do (yet)

- No CO₂ / RH sensors (`0x2D` reports none fitted), no SUSPEND/RESUME exchange.
- No LON module, no programme-2 week clock, no start-up burst from the mainboard
  (undocumented).
- No legacy temperature registers 0x58–0x5C (which set a machine uses is discovered
  from traffic, not assumed).
- Broadcast writes to 0x10 are applied like unicast writes — assumed.
- The model does not poll the panel. Whether the real mainboard does is an M3 question.
- Frost protection raises no fault code: none is documented for exchanger frost (0x09 is
  the water-coil fault); it only sets the supply-fan bit of 0x08 (IO_MULTI_2).
- The service (bit 7) and filter (bit 4) indicator bits of 0xA3 are never set; the month
  counter 0xAB decrements but the reminder indicator is not modelled.

## Guard

`scripts/check-machine-regs.py` (run by CI) cross-checks `vallox_machine_regs.h`
against `docs/research/protocol.md`: writability per section, NTC-encoded
registers in the degree table, and registers the document does not describe.
It currently warns about 0x6C and 0x6E (flags 1 and 3): they are in
`vallox_protocol.h` but protocol.md has no row for them, so the model answers
them with 0 — a documented gap, not a claim.

## Using it

```c
vlx_machine_t m; vlx_machine_init(&m);
vlx_machine_feed(&m, rx, n);                    // bytes heard on the bus
n = vlx_machine_tick(&m, now_ms, tx, sizeof tx); // send these
m.p.t_outdoor = -15.0f; m.p.time_scale = 60.0f; // side panel knobs
vlx_machine_fault(&m, VLX_FAULT_SUPPLY_AIR_SENSOR);
```

Tests: `firmware/test/host/test_vallox_machine.c` and `test_e2e_membus.c`.

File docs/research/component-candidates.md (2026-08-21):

# Component candidates

Parts considered before the schematic exists. This is not a bill of materials —
it is the reasoning that will produce one, written down while the alternatives are
still visible.

**Everything here is conditional.** Two measurements decide the power stage, and
neither has been made yet: whether the 21 V panel rail is isolated from mains (M1)
and how much current it can supply (M2). See
[measurement-plan.md](measurement-plan.md). Where a choice depends on a measurement,
the dependency is written next to it rather than resolved by guessing.

## Selection rules used

1. **Cheapest part that meets the requirement**, not the cheapest part.
2. **In the assembler's own inventory.** A part that has to be bought on the open
   market adds handling cost and lead time to a small run. JLCPCB *Basic* parts have
   no feeder setup fee; *Extended* parts do, currently around $3 per distinct part
   per order.
3. **Stock checked live, and checked again at order time.** Prices and stock below
   were read from the JLCPCB catalogue on **2026-08-21** and will have moved. They
   are recorded to make the reasoning checkable, not as a quotation.
4. **A second source for anything that is not a commodity passive.**
5. Prices are single-unit catalogue prices in USD. At a build of 5–10 boards the
   feeder fees dominate, which is why the Basic/Extended column matters more than
   the price column.
6. **An existing KiCad footprint and 3D model, whenever a part that has both meets
   the requirement.** Added 2026-08-22. A drawn footprint has to be validated
   against the manufacturer's land pattern; a missing 3D model is not visible as a
   problem until the enclosure has been designed around a guess. Checked on disk,
   because two of the library search tools give false negatives. Full rule and its
   three cases in [`../../hardware/docs/decisions.md`](../../hardware/docs/decisions.md).

## Revised 2026-08-22

The tables below carry live figures re-read on 2026-08-22. Two part choices changed
as a result, both recorded in `decisions.md`:

- **U1** — `ESP32-C3-MINI-1-N4` → `ESP32-C3-WROOM-02-N4`. The MINI had neither a
  footprint nor a 3D model, and its price rose from $2.79 to $3.84 while the
  alternative fell to $2.89. The argument for the MINI was price, and price
  inverted.
- **SW1–4** — `TS-1187A-B-A-B` → 6 × 6 mm gullwing, default `K2-6639SP-A4SC-04`.
  The TS-1187A family has a footprint but no 3D model in any library.

Two parts keep their choice and gain a library task instead: the USB-C receptacle
and the display, both of which need a STEP model adding to `mironet-hw-lib`.

The reasoning written before those changes is left standing below rather than
edited, so that what was thought at the time stays readable.

## Where the cost actually is

At these quantities the radio module is roughly 60 % of the parts cost and
everything else is noise. That has a consequence worth stating early: optimising the
passives is not where the money is, and the two places worth real attention are the
module choice and the number of distinct Extended parts.

## Architecture being costed

The board takes the place of the panel on the same five wires. It is the only
controller on the panel side of the bus.

```
 the five wires that fed          this board, on the wall where the panel was
 the original panel
 ┌────────────────────┐
 │ 1  +   22 V meas. ─┼──▶ reverse-polarity block ──▶ buck 3.3 V ──┬──▶ ESP32-C3
 │ 2  −               ┼──▶ return                                  │     │ UART+RTS
 │ 3  A               ┼──▶ PPTC ─┬─▶ RS-485, 1/8 UL, slew limited ◀─┘     │
 │ 4  B               ┼──▶ PPTC ─┤                                        │
 │ 5  M   signal gnd ─┼──────────┴─ TVS to bus ground                     │
 └────────────────────┘                                    local controls ─┤
                                                           USB-C (bench) ──┘
```

Half duplex, one UART, driver enable from the UART's RTS pin so the direction
change is timed by the peripheral rather than by software.

That last point is a deliberate answer to a known field failure. The community guide
reports that RS-485 modules **without** automatic direction control cause the Vallox
to show `Väylävika` (bus fault), and the usual fix is to buy a module with a
one-shot timer on the direction pin. Those timers are set for one baud rate and are
approximate. The ESP32 UART has a hardware RS-485 half-duplex mode that asserts the
driver enable around the transmission exactly, and using it costs nothing.

## Variant A — bus-powered, non-isolated

The baseline. Valid **only if M1 confirms the 21 V rail is a protective extra-low
voltage supply isolated from mains.** In that case the board has exactly one
galvanic connection to the world — the bus itself — and an isolation barrier inside
it would protect nothing during normal operation.

Stock and price re-read live 2026-08-22. `FP` = KiCad footprint exists, `3D` = 3D
model exists, both checked on disk.

| Ref | Function | Candidate | LCSC | Stock | $/pc | Class | FP | 3D |
|---|---|---|---|---|---|---|---|---|
| U1 | MCU + radio | **ESP32-C3-WROOM-02-N4** | C2934560 | 2 255 | 2.886 | extended | ✔ | ✔ |
| U2 | 21 V → 3.3 V buck | TPS54202DDCR | C191884 | 180 809 | 0.226 | extended | ✔ | ✔ |
| U3 | RS-485 transceiver | THVD1400DR | C3235232 | 10 443 | 0.237 | extended | ✔ | ✔ |
| D1 | Reverse-polarity block | SS34 | C8678 | 3 557 042 | 0.030 | **basic** | ✔ | ✔ |
| D2 | Bus transient clamp | PSM712-LF-T7 (SM712) | C32677 | 151 478 | 0.298 | **basic** | ✔ | ✔ |
| F1, F2 | Bus overcurrent, 100 mA / 60 V | JK-mSMD010-60 | C1884489 | 74 360 | 0.035 | extended | ✔ | ✔ |
| L1 | Buck inductor, 10 µH | FNR6045S100MT | C168076 | 31 949 | 0.073 | extended | ✔ `L_Changjiang_FNR6045S` | ✔ |
| J2 | USB-C 2.0 receptacle | TYPE-C-31-M-12 | C165948 | 336 394 | 0.161 | extended | ✔ exact part | ✘ **task** |
| J1 | 5-pole field terminal | KF128 family, 3.81 or 5.08 mm | C474933 and family | — | ~0.30 | extended, through-hole | choose by coverage | — |
| — | Bulk, decoupling, dividers, LEDs | 0402/0603 basic parts | — | — | ~0.38 total | **basic** | ✔ | ✔ |

Parts cost lands around **$4.85 per board**, with the module at $2.89 of it. The
local interface adds about $2.35 to the assembled board and about $6.20 to the
finished device — see below. Almost all of that increase is the four C&K switches,
and the reasoning for paying it is in `decisions.md`.

**Changed since the 2026-08-21 snapshot.** U1 was `ESP32-C3-MINI-1-N4` (C2838502)
at a recorded $2.79; it is now $3.84 with no footprint and no 3D model, and the
alternative has fallen to $2.89 with both — see `decisions.md`. U3 is $0.08 cheaper
but its stock fell from 93 954 to 10 443, which is a drop worth watching rather
than acting on.

### Why each of those

**U1 — ESP32-C3-MINI-1-N4, not the ESP32-S3 the scaffolding assumed.**
The workload is one 9600 baud UART, a Wi-Fi client and an MQTT connection. There is
no second core to use, no PSRAM to fill and no camera or USB host to drive. The C3 is
cheaper, draws less, and has the same native USB Serial/JTAG the S3 has, so it needs
no USB-to-UART bridge either. Given that the gating risk on this project is how much
current the bus can give (R2), the lower-power part is also the lower-risk part.

The module rather than the bare chip: a pre-certified module carries the radio
approval. A reference design that tells a reader to build one and put it on their
wall should not hand them an uncertified radio.

Second source: ESP32-C3-WROOM-02-N4 (C2934560, 3 702 in stock, $3.11) — different
footprint, so it is a design-time alternative, not a drop-in.

**U2 — TPS54202DDCR.** 4.5–28 V in, 2 A, integrated switch, and the number that
matters: **45 µA quiescent**. On a rail whose current budget is the main unknown, a
regulator that idles at milliamps is a bad trade. The JLCPCB *Basic* wide-input buck
is the TPS5430 (C9864, $0.81), which draws 4.4 mA quiescent — roughly a hundred
times more, and about 90 mW burned at 21 V doing nothing. Paying $3 of feeder fee to
avoid that is the right way round.

The caveat is the 28 V input ceiling. 21 V nominal leaves 7 V of margin, which is
comfortable for a regulated rail and thin for an unregulated one. **If M1 shows the
rail is unregulated or exceeds about 24 V at no load, this part is replaced** by
MP2459GJ-Z-MS (C45367195, 14 102 in stock, $0.40), which takes 55 V and costs 730 µA
of quiescent instead of 45 µA.

**U3 — THVD1400DR.** Chosen against the part it replaces rather than against the
price list. The original panel's transceiver was read off the board in the
photographs: a **MAX487**, which is 1/4 unit load, 48 kΩ receiver input impedance,
slew-rate limited, specified to 250 kbps. Three requirements follow:

- **Bus loading no heavier than the original.** The machine's driver was specified
  against a 1/4-unit-load panel. THVD1400 is 1/8 unit load, so the machine sees an
  easier bus after the swap, never a harder one.
- **A slew-rate limited driver.** The original limits its slew rate at 9600 baud on
  a cable that runs through a house. Fitting a 10 Mbps part instead would raise
  emissions for no benefit whatsoever.
- **Integrated fail-safe** on an open, short or idle bus. This removes two bias
  resistors and, more usefully, removes a question: whether the machine biases the
  bus stops mattering for the receiver's idle state.

Datasheet figures from TI SLLSF78B: 3–5.5 V supply, bus pins −16 V to +16 V
absolute maximum, ±12 kV IEC contact ESD, 700–900 µA quiescent while receiving.

The cheaper option is SP3485EN-L/TR (C8963, 327 071 in stock, $0.176) and it is a
JLCPCB *Basic* part, so it saves the feeder fee as well as the 14 cents. It is the
fallback, not the default — and if it is ever substituted, it has to be checked
against all three requirements above and not just against the pinout.

Note what the transceiver choice does **not** do: its bus pins are rated to ±16 V,
and a miswired supply would put 22 V on a data line. The fuse and the clamp below
are what handle that. Picking a tougher transceiver is not a substitute for them.

**D1 — SS34.** Reverse polarity on the 21 V pair is the failure the Vallox manual
puts in bold. A series Schottky is the crude answer and, at this current, the right
one: at an expected 10 mA average draw the forward drop is around 0.25 V and the
loss is a few milliwatts. An ideal-diode P-channel MOSFET would drop less and cost
more, and there is nothing here to spend that saving on. Basic part, three and a half
million in stock, three cents.

**D2 and F1/F2 — the bus fault path.** This is the part of the design that answers
the manufacturer's warning properly. The SM712 is a TVS made specifically for RS-485:
asymmetric, clamping the bus lines to about +13.3 V and −8.5 V, which sits just
outside the RS-485 common-mode window and just inside the SP3485's absolute maximum
of −7.5 V to +12.5 V. On its own it would be destroyed by 21 V applied continuously
to a data line, so it is paired with a 100 mA / 60 V resettable fuse in each line:
the TVS survives the transient, the fuse trips and turns a wiring mistake into an
inconvenience instead of a dead board.

`PSM712-LF-T7` at $0.298 is the Basic version; functionally identical Extended parts
sell for $0.03. Which is cheaper depends entirely on batch size — below roughly 12
boards the Basic part wins because it avoids the feeder fee, above that the Extended
one does. Decide at order time, from the actual quantity.

**L1 — FNR6045S100MT.** 10 µH, shielded, 2.7 A saturation, 62 mΩ, in a 6 × 6 mm
package. Oversized for a 500 mA load on purpose: the margin is free at seven cents
and the low DCR helps efficiency at the light loads this board actually runs at.

**J1 — the field terminal.** Five poles, screw or pluggable, in the manufacturer's
order `+ − A B M`, because that is exactly what is on the original panel's board
and the installer is transferring wires one at a time from one terminal to the
other. Landing 0.5 mm² solid conductors rules out anything spring-loaded and fine.

**The silkscreen labels by function, not by colour.** The manual's colour code is
orange-and-white NOMAK; the cable actually installed on the target machine is red,
blue, green, yellow and white. Every published guide for this bus describes the
wiring by colour, and in this house the colours are wrong. Printing a colour on the
board would be printing a mistake.

It is also the one through-hole part. JLCPCB charges per through-hole joint, so five
poles is a real line item, and the alternative — hand-soldering one connector — is
the difference between a fully assembled board and a board that needs a soldering
iron. For a reference project that tells people to build one, paying for the joints
is the right answer.

**Bulk capacitance.** Sized from the burst, not from a rule of thumb. Calculated:

- ESP32-C3 transmit peak is about 350 mA at 3.3 V, so 1.16 W, drawn in bursts of a
  few milliseconds.
- Through an 85 % efficient buck from 21 V that is about 65 mA on the bus side.
- Holding that for 2 ms within a 0.6 V droop needs `C = I·t/ΔV` ≈ 220 µF.

A 220 µF / 35 V part covers it with margin. **This calculation is not a measurement**
— the real burst profile comes from M2, and if the rail turns out to be stiffer or
weaker than assumed, this number moves.

### Deliberately not fitted, but footprinted

- **120 Ω bus termination**, behind a solder bridge, unfitted by default. The
  replacement should present the bus the panel presented, so the question is what
  the original did as much as what the machine expects. Answered by M1 and by a
  closer look at the original board now that it is coming off the wall.
- **Fail-safe bias resistors.** Footprinted and unfitted. The chosen transceiver
  biases itself, and adding external bias to a bus the machine may already bias is
  a way to make things worse.
- **Common-mode choke** on A/B. Cheap, helps conducted emissions, and easy to short
  out with two zero-ohm links if it turns out to be unnecessary.

## Local interface

Costed in full in [user-interface.md](user-interface.md), which compares an LED bar
against a 0.96" OLED against a colour TFT with live prices, power arithmetic and
lifetime. Summary of what it lands on:

| Ref | Function | Candidate | LCSC | Stock | $/pc | FP | 3D |
|---|---|---|---|---|---|---|---|
| DS1 | 2.0" 320×240 colour IPS, ST7789, SPI | HS20HS072RX | C5329582 | 657 | 3.772 | n/a — off board | ✘ **task** |
| J3 | FPC connector, 0.5 mm | HC-FPC-05-10-30RLTAG family | C5213742 | 5 932 | 0.179 | verify vs `Hirose_FH12-30S-0.5SH` | ✔ |
| SW1–4 | Tactile switch, 6 × 6 mm — `−` `+` `OK` `←` | **PTS645SM43SMTR92LFS** | C221880 | 1 421 | 0.532 | ✔ `SW_SPST_PTS645Sx43SMTR92` | ✔ H4.3 exact |
| R-ladder | Four 0402 resistors, buttons onto one ADC pin | — | — | — | 0.002 | ✔ | ✔ |
| D3–5 | Indicator LEDs, 0603 | 19-217 family | C2986059 and family | — | 0.018 | ✔ | ✔ |
| — | Backlight drive | open — boost driver ~$0.30, or a constant-current sink from a 5 V rail ~$0.05 | — | — | — | — | — |

**Buttons changed 2026-08-22.** Was `TS-1187A-B-A-B` (C318884, 5.1 × 5.1 mm, 1.6 N,
Basic, $0.0197): footprint present, **no 3D model in any library**. The board is now
laid out on the PTS645 6 × 6 gullwing land pattern, and the fitted part is C&K's own
`PTS645SM43SMTR92LFS` — 1.6 N, which is the force the printed flexure wanted, and
4.3 mm, which is exactly the height of the KiCad 3D model.

Fitting the genuine part rather than a clone retires the pad-span check that this
document briefly listed as blocking: `SW_SPST_PTS645Sx43SMTR92` is C&K's own land
pattern from C&K's datasheet, so the footprint and the part specification are the
same document. It also gives a second source outside LCSC, which no clone does.

The cost is real — $2.13 a board against $0.18 for the cheapest clone. Cheaper parts
on the same pads, if a batch ever makes that matter: `K2-6639SP-A4SC-04` (C879454,
2.5 N, 4.3 mm, $0.0456, 54 370 in stock) and `ZX-QC66-4.3TP` (C7470150, 2.6 N,
4.3 mm, $0.0288). Substituting one brings the pad-span check back with it.

A 0.96" OLED was the first choice and it was wrong: it shows eight characters by
three lines at arm's length, which is a readout rather than a menu, and the reason
for choosing a display at all was to present a menu. Colour TFT also costs three to
five times less per square millimetre than mono OLED. The full arithmetic is in
[user-interface.md](user-interface.md).

**About $0.30 of this is on the assembled board**, plus the backlight drive. The
display is a bare glass panel with an FPC tail: the fab solders the connector, the
display is plugged in afterwards. It is not part of the PCBA order, which means
the same board takes either a display or nothing.

**The backlight is the open item.** Four white LEDs in parallel at 80 mA typical
cannot run from 3.3 V. The cheap answer is a 5 V intermediate rail with a
PWM-dimmed current sink, but that changes the power chain, so it is decided with
M2a rather than assumed here.

### The buttons, and the pin budget that shaped them

Four switches: `−` and `+` change fan speed directly on the home screen, `OK`
enters the menu and confirms, `←` backs out. Long-press as the only way back is
rejected — it is a convention that has to be taught, and this device gets used
twice a year.

They go on a **resistor ladder into one ADC channel**, not four GPIOs, and that is
not a flourish. ESP32-C3-MINI-1 exposes fifteen pins, two of which are USB:

| Function | Pins |
|---|---|
| RS-485 TX, RX, DE | 3 |
| Display SPI: SCK, MOSI, CS, DC | 4 |
| Display reset — RC from the rail | 0 |
| Backlight PWM | 1 |
| Indicator LEDs | 3 |
| Buttons, via the ladder | 1 |
| **Total** | **12 of 13** |

Four discrete button GPIOs would need sixteen and does not fit. The ladder lands
on GPIO3 or GPIO4 — ADC1, because ADC2 is unusable with Wi-Fi running, and neither
is a strapping pin, so a button held at power-up cannot change the boot mode.

The chosen part matters less than the family: **every TS-1187A shares the same
5.1 × 5.1 mm four-pad footprint** and they differ only in plunger height
(1.5–3.0 mm) and force (1.6 N or 2.6 N). The board is laid out once and the height
is chosen when the enclosure exists. `TS-1187A-B-A-B` is the Basic part with 1.68
million in stock, and its 1.5 mm / 1.6 N combination is the one that suits a thin
printed flexure — no holes in the front panel, which matters beside a machine
that moves dusty air.

Not chosen, with reasons: **capacitive touch**, because ESP32-C3 has no touch
peripheral at all and because a control with no tactile feedback should not be the
only way to run a household's ventilation; **a rotary encoder**, because
`EC11L1525G01` at $1.27 is sixteen times the price of the whole button set, is
through-hole, and is the most wear-prone part that could go on a board meant to
outlast the machine. Both are written up in
[`../../hardware/docs/decisions.md`](../../hardware/docs/decisions.md).

**No BOOT or RESET buttons.** The C3's native USB-Serial-JTAG resets and enters
download mode over USB. EN and GPIO9 get test pads instead.

The three indicator LEDs stay regardless of the display decision — power, bus
activity and fault, readable from the doorway, six cents, and they answer "is it
alive" without waking anything.

## The enclosure

The panel is mounted **under the machine**, in a technical space. There is no
footprint to match and nothing to cover: the manufacturer's 90 × 110 × 23 mm is a
reference point, not a requirement.

What that permits is a board shaped around its own contents rather than around a
hole in a wall. What it still demands is a display window if a display is fitted,
which is the hardest feature to print well on an FDM part, and cable entry that
suits a cable arriving from the machine above.

## Variant B — isolated bus front end

Required if **M1 shows the panel rail is not isolated from mains**, and worth
considering anyway if the board is expected to be plugged into USB while it is wired
to the machine.

| Ref | Function | Candidate | LCSC | Stock | $/pc |
|---|---|---|---|---|---|
| U3 | Isolated RS-485 transceiver | CA-IS3082CWX | C41784141 | 196 | 0.937 |
| U4 | Isolated 5 V for the bus side | B0505S-1W | C7465127 | 45 180 | 0.633 |

Delta over variant A is roughly **+$1.60 per board**, plus board area, plus a second
regulator stage to make the 5 V the isolation module needs.

The stock figure on the isolated transceiver is the problem: 196 pieces is not a
supply, it is a coincidence. If this variant is chosen, the part is re-selected
against stock at that time rather than taken from this table.

Note also what this variant does *not* buy. If the board is powered from the bus,
isolating the transceiver only moves the barrier — the power still crosses it. A
genuinely isolated design means an isolated DC-DC carrying the whole board's power,
which is the +$1.60 above, or an external supply, which makes the board ordinary.
Variant B is a contingency, not an upgrade.

## Rejected, and why

| Considered | Rejected because |
|---|---|
| ESP32-S3-WROOM-1 | $1 dearer than the C3 for capability this device has no use for, and a higher idle draw on a rail whose budget is the main risk |
| Bare ESP32-C3 chip with a PCB antenna | Saves about $1.50 and costs radio certification. Wrong trade for a design other people are told to build |
| TPS5430 (the Basic wide-input buck) | 4.4 mA quiescent, about 90 mW at 21 V doing nothing, on the one rail that cannot spare it |
| MAX485 and its clones | 5 V part; the whole board is 3.3 V |
| SP3485EN-L/TR as the default transceiver | Cheaper and a Basic part, so it saves the feeder fee too. Kept as the fallback, not the default: the original panel uses a 1/4-unit-load slew-limited MAX487, and matching that is worth 14 cents |
| RS-485 module with an automatic direction timer | The reported cause of `Väylävika` reports is direction timing, and the ESP32 UART already does it in hardware and exactly. Buying a module to solve a problem the MCU does not have is backwards |
| Ideal-diode controller for reverse polarity | Correct at amperes. At ten milliamps a three-cent Schottky is the same answer for less money and fewer parts |
| Barrel jack and an external supply | Removes the reason this device is better than a development board taped inside the machine |

## Open, and blocking

1. **M1 and M2.** The rail's isolation and its current capability. Variant A or B,
   TPS54202 or MP2459, and the bulk capacitor all hang on these.
1b. **M2a — what the original panel draws.** Two minutes with an ammeter in series
   with the + wire, before the panel comes off the wall. Because the panel's
   regulator is linear, its input current is the rail's demonstrated capability.
   It is the cheapest way to close the project's central open question.
1c. **Local interface — decided 2026-08-21.** A 2.0" 320×240 colour IPS, four
   buttons and three LEDs. Analysed in [user-interface.md](user-interface.md); the
   earlier recommendation of a sleeping 0.96" OLED was wrong and is superseded
   there. What remains open under it is the backlight drive, below.
1d. **Backlight drive.** Four white LEDs in parallel, 80 mA typical, which will not
   run from 3.3 V. Boost driver at about $0.30 against a 5 V intermediate rail with
   a PWM-dimmed current sink at about $0.05. The cheaper answer changes the whole
   power chain, so it is decided together with M2a.
2. **The through-hole terminal.** Cost per joint at the intended batch size decides
   whether it is assembled or shipped loose. Choose the part from one that has a
   footprint and a 3D model, per selection rule 6.
3. **Basic versus Extended for the SM712.** Decided by batch size at order time.
4. **Two 3D models to obtain**, into `mironet-hw-lib`: the USB-C receptacle
   (`USB_C_Receptacle_HRO_TYPE-C-31-M-12` has the exact footprint but no model) and
   the display glass, which needs a model for the enclosure even though it is not
   on the PCBA. Replacements that already have models were searched for and do not
   exist at a sensible price — the only JLCPCB-stocked USB-C with a model is
   $1.334 against $0.161 for 24 pins of USB 3.2 this design does not use, and no
   bare IPS glass has a footprint at all because it does not mount to the board.
   Both are now issues on `mironet-hw-lib`, with that search recorded so it is not
   repeated.
6. **Order of work: components, then layout, then enclosure.** Decided 2026-08-22.
   This is the reverse of the earlier note here, which said the enclosure comes
   first because the terminal block position and the antenna keep-out are enclosure
   decisions. Those two remain the cost of this order and are handled by treating
   them as layout constraints written down in advance rather than as things the
   enclosure gets to move later: the terminal block goes on the edge the cable
   arrives at, and the module's antenna keep-out comes from the WROOM-02 datasheet
   and is kept clear of copper and of any metal fastener. The enclosure draft is
   then generated from the finished board — the first STEP reads the board outline
   and the hole pattern out of KiCad rather than having them measured by hand.

## Which fab, and an inconsistency worth naming

Every part above was checked against the **JLCPCB** catalogue, because the whole BOM
sits in that assembler's own inventory and none of it is safety-critical — which is
exactly the condition under which JLCPCB is the cheaper route for a small batch.

`project.yaml` currently says `assembly.fab: pcbway`, which is the workspace default
and does not match that analysis. It is left alone deliberately: the order tooling
generates a PCBWay package and nothing else today, so changing the field would
produce a package for the wrong fab rather than fix anything. The route is decided
at the fabrication stage, and if it is JLCPCB then the tooling gap gets closed first.

## Stock check before ordering

The stock figures above are a snapshot and will be stale by the time a board is
ordered. The pre-order gate in the workspace rules re-runs the whole BOM against
live stock, checks the manufacturer part number against the designator type, and
flags every Extended part — that gate is what decides whether the board is ordered,
not this document.

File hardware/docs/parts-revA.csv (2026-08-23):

Reference | Manufacturer | MPN | LCSC | DNP
C1 | Nichicon | UCD1V221MNL1GS | C136294
C2 | Samsung Electro-Mechanics | CL21A225KBQNNNE | C377773
C3 | YAGEO | CC0603KRX7R9BB104 | C14663
C4 | Samsung Electro-Mechanics | CL21A226MAQNNNE | C45783
C5 | Samsung Electro-Mechanics | CL21A226MAQNNNE | C45783
C7 | Samsung Electro-Mechanics | CL10A106KP8NNNC | C19702
C8 | YAGEO | CC0603KRX7R9BB104 | C14663
C9 | Samsung Electro-Mechanics | CL10A105KB8NNNC | C15849
C10 | Samsung Electro-Mechanics | CL10A106KP8NNNC | C19702
C11 | YAGEO | CC0603KRX7R9BB104 | C14663
C12 | YAGEO | CC0603KRX7R9BB104 | C14663
C13 | Samsung Electro-Mechanics | CL10A105KB8NNNC | C15849
D1 | MDD | SS34 | C8678
D2 | ProTek Devices | PSM712-LF-T7 | C32677
D3 | MDD | SS34 | C8678
D4 | XINGLIGHT | XL-1608SYGC-06 | C965805
D5 | Hongli Zhihui | KT-0603R | C2286
D6 | Nationstar | NCD0603Y1 | C84268
F1 | JK | JK-mSMD010-60 | C1884489
F2 | JK | JK-mSMD010-60 | C1884489
J1 | Dorabo | DB128V-5.08-5P-GN-S | C2927513
J2 | Korean Hroparts Elec | TYPE-C-31-M-12 | C165948
L1 | Changjiang Microelectronics | FNR6045S220MT | C168080
Q1 | Alpha & Omega Semiconductor | AO3400A | C20917
R1 | UNI-ROYAL | 0603WAF1003T5E | C25803
R2 | UNI-ROYAL | 0603WAF1502T5E | C22809
R3 | UNI-ROYAL | 0603WAF1003T5E | C25803
R4 | UNI-ROYAL | 0603WAF1332T5E | C25952
R5 | UNI-ROYAL | 0603WAF1200T5E | C22787 | yes
R6 | UNI-ROYAL | 0603WAF1001T5E | C21190 | yes
R7 | UNI-ROYAL | 0603WAF1001T5E | C21190 | yes
R8 | UNI-ROYAL | 0603WAF1002T5E | C25804
R9 | UNI-ROYAL | 0603WAF1002T5E | C25804
R10 | UNI-ROYAL | 0603WAF1002T5E | C25804
R11 | UNI-ROYAL | 1206W4F270JT5E | C17946
R12 | UNI-ROYAL | 0603WAF1000T5E | C22775
R13 | UNI-ROYAL | 0603WAF1002T5E | C25804
R14 | UNI-ROYAL | 0603WAF5101T5E | C23186
R15 | UNI-ROYAL | 0603WAF5101T5E | C23186
R19 | UNI-ROYAL | 0603WAF1002T5E | C25804
R20 | UNI-ROYAL | 0603WAF1001T5E | C21190
R21 | UNI-ROYAL | 0603WAF1002T5E | C25804
R22 | UNI-ROYAL | 0603WAF1002T5E | C25804
R23 | UNI-ROYAL | 0603WAF1501T5E | C22843
R24 | UNI-ROYAL | 0603WAF3301T5E | C22978
R25 | UNI-ROYAL | 0603WAF6801T5E | C23212
R26 | UNI-ROYAL | 0603WAF1001T5E | C21190
R27 | UNI-ROYAL | 0603WAF1001T5E | C21190
SW1 | C&K | PTS645SM43SMTR92LFS | C221880
SW2 | C&K | PTS645SM43SMTR92LFS | C221880
SW3 | C&K | PTS645SM43SMTR92LFS | C221880
SW4 | C&K | PTS645SM43SMTR92LFS | C221880
U1 | Espressif Systems | ESP32-C3-WROOM-02-N4 | C2934560
U2 | Texas Instruments | TPS54202DDCR | C191884
U3 | Microne | ME6211C33M5G-N | C82942
U4 | Texas Instruments | THVD1400DR | C3235232

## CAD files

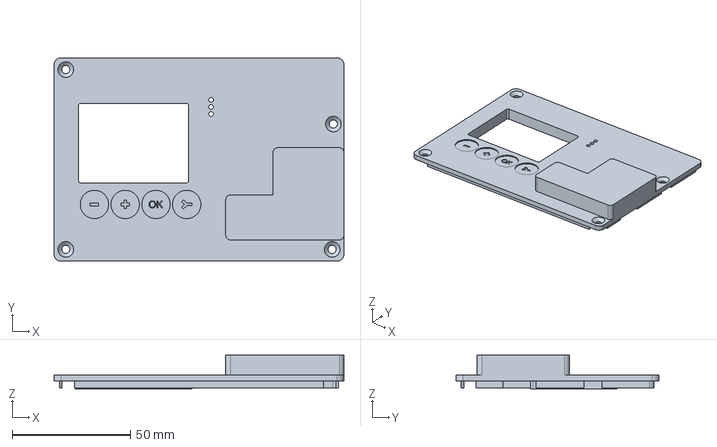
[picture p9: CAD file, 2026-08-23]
mechanical/step/enclosure-cover-draft.step
122.6 x 86.0 x 14.3 mm

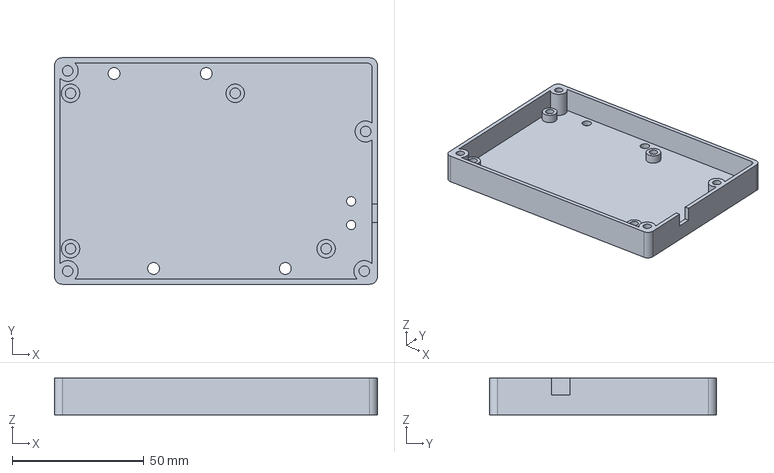
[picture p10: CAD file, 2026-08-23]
mechanical/step/enclosure-base-draft.step
122.6 x 86.0 x 14.0 mm

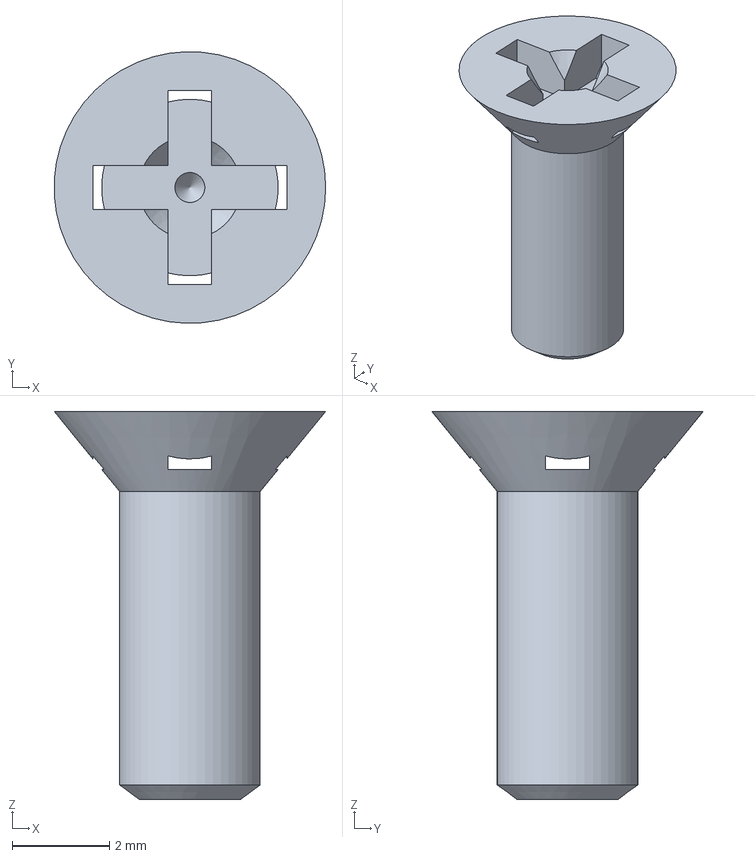
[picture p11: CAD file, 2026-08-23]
mechanical/step/m3x8-countersunk-draft.step
5.59 x 5.60 x 8.00 mm

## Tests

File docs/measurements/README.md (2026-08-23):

# Measurements

Every claim about this device is backed by a measurement recorded here. One file
per question, named `YYYY-MM-DD-<topic>.md`.

The plan that produces the reports is
[`../research/measurement-plan.md`](../research/measurement-plan.md).

| Report | Answers |
|---|---|
| [2026-08-21-panel-identification.md](2026-08-21-panel-identification.md) | M0 (partly) and the supply-voltage row of M1: which panel, what is on its terminals, 22 V on the pair |
| [2026-08-22-panel-current.md](2026-08-22-panel-current.md) | M2a: the factory panel draws 450 mA continuous, 700 mA momentary — conditions still to be recorded |
| [2026-08-22-rail-voltage-no-load.md](2026-08-22-rail-voltage-no-load.md) | M1, no-load row: 22.8 V with the panel disconnected; the buck stays TPS54202 |

## Instruments used

The instrument matters: a reader judges a ripple figure differently depending on
whether it came from a 20 MHz handheld scope or a bench instrument with proper
probing. Model numbers go in as each instrument is first used, not later.

| Instrument | Model | Used for |
|---|---|---|
| Multimeter, CAT III | not yet recorded — used for the 22 V and the 450/700 mA readings, model to be added | M1 — is the panel bus safe to touch, and what is on it; M2a — panel current |
| Oscilloscope | not yet recorded | M1 rail ripple, M3 bus waveform, M4 frame timing |
| Differential or isolated probe | not yet recorded | M1, only if the rail turns out not to be isolated |
| Electronic load or resistor decade | not yet recorded | M2 — how much current the 21 V rail can give |
| USB RS-485 adapter, transmit disabled | not yet recorded | M3 — passive capture |
| Logic analyser | not yet recorded | M3, M4 — byte-level timing alongside the scope |
| Reference thermometer | not yet recorded | Checking the NTC table against reality |
| Infrared thermometer or thermocouple | not yet recorded | Temperature under load, enclosure closed |

The RS-485 adapter is the one instrument whose behaviour has to be verified
before it is used: it must be incapable of transmitting. That check happens on
the bench against a second adapter and it is part of the M3 report, not a
precondition anyone is trusted to remember.

## Required before release

- [ ] Current consumption in every operating mode
- [ ] Rail voltages and ripple under load
- [ ] Start-up behaviour: rise time, sequencing, inrush
- [ ] Interface signal integrity and error rate over a long run
- [ ] Temperature under load, enclosure closed
- [ ] Wireless range with the enclosure in place
- [ ] 72 h continuous run without a reset
- [ ] Reverse-polarity survival on the 21 V input, and 21 V applied to a data line

The last item is not a general requirement, it is specific to this device: the
manufacturer states that miswiring the positive conductor destroys the factory
panel, and surviving that is a design claim this project makes. A claim of that
kind needs a bench test with a photograph of the setup and the board working
afterwards.

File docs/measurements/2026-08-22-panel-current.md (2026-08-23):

# Current drawn by the factory panel from the 21 V rail (M2a)

| | |
|---|---|
| Date | 2026-08-22 |
| Hardware revision | none — no board exists |
| Firmware version | none |
| Ambient conditions | indoor, machine running; not recorded further |
| Measured by | Miro Eilola |
| Report written from | a reported reading, not from witnessing the measurement |

## Question

How much current does the original Vallox DIGIT SE LED panel draw from the supply
pair (terminals 1 + / 2 −)? This is measurement **M2a** in
[`../research/measurement-plan.md`](../research/measurement-plan.md): the panel's
draw is current the rail has demonstrably been delivering, so it is the floor of
the rail's capability without loading the rail with anything new.

## Setup

Ammeter in series with the + conductor at the panel terminal, factory panel
connected and operating, machine running.

**Not recorded — to be filled in by the person who measured:** instrument make,
model and range; whether the meter was in the + or − conductor; machine fan speed
and heating state; what the panel's LEDs were showing; how long the momentary
peak lasted and what caused it (power-on, a button press, an LED change); whether
both figures are DC readings.

## Results

| Measurement | Value | Notes |
|---|---|---|
| Panel supply current, continuous | **450 mA** | reported reading |
| Panel supply current, momentary peak | **700 mA** | reported reading; duration and trigger not recorded |
| Supply voltage | 22 V DC | from the 2026-08-21 report, load state not recorded there either |

Derived, not measured: 450 mA × 22 V ≈ **9.9 W** continuous, 700 mA × 22 V ≈
15 W momentary, drawn from the bus by the panel alone.

## Interpretation

1. **The rail supplies the replacement with room to spare.** The board's own
   draw at the rail is on the order of 0.1–0.2 A (ESP32-C3 Wi-Fi peaks, 80 mA
   backlight at 5 V, RS-485, through a buck at ~85 %). The rail has been feeding
   two to four times that, continuously, for two decades. Risk R2 in
   [`../research/risks.md`](../research/risks.md) is closed by this reading, subject
   to the conditions above being filled in.
2. **The 60 mA prior was wrong by 7×.** [`../research/user-interface.md`](../research/user-interface.md)
   inferred ~60 mA / 1.3 W from the size of the regulator's heatsink. That
   inference is withdrawn there and here. It was an estimate labelled as one, and
   this is what M2a was for.
3. **"Draws less while doing more" is now a measurable 2–4× claim**, not a hope.
   The bring-up report compares the finished board's rail current against 450 mA.
4. **The no-load rail voltage matters more than it did.** 22 V was read with
   (presumably) a 10 W load on an unregulated, rectified 16 VAC secondary. Remove
   the panel and the rail rises — by how much depends on the transformer's
   regulation, and the provisional buck's operating maximum is 28 V. The
   "factory panel disconnected" row of M1 is now the measurement that decides
   the buck, and it is a one-minute job.

## Deviations

- **The reading disagrees with the documents, and the disagreement is recorded
  rather than explained away.** The Vallox diagrams (see
  [`../research/sources.md`](../research/sources.md)) put the control supply on a
  **14 VA** transformer with a **T800 mA** fuse on its 16 VAC secondary, shared
  with the mainboard and rated for up to three panels. One panel at ~10 W DC is
  roughly 0.7–0.9 A rms on that secondary before the mainboard's own share. Either
  this machine's transformer is larger than the spare-part listing (a 1.3 A / 16 V
  variant exists from 04/2002), or most of the panel current bypasses the small
  regulator (LEDs fed from the rail, which the heatsink size supports), or the
  reading carries an artifact (AC range, shunt burden, inrush read as
  continuous). The first two are consistent with each other; the third is ruled
  out only by recording the instrument and repeating the reading. **None of the
  three changes the conclusion in 1.**
- A linear regulator passing 450 mA across 17 V would dissipate 7.6 W; the
  folded heatsink in the 2026-08-21 photographs cannot hold that. Most of the
  panel's current therefore does not go through the regulator. Worth a look at
  the panel board when it is next open: where the LED strings are fed from.
- Measurement conditions not recorded — see *Setup*. The figures are recorded
  as reported and are enough for the conclusions drawn; they are not enough for
  the datasheet until the instrument and the load state are attached.

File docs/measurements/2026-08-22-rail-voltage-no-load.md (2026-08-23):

# Supply rail voltage with the factory panel disconnected (M1, no-load row)

| | |
|---|---|
| Date | 2026-08-22 |
| Hardware revision | none — no board exists |
| Firmware version | none |
| Ambient conditions | indoor, machine running; not recorded further |
| Measured by | Miro Eilola |
| Report written from | a reported reading, not from witnessing the measurement |

## Question

What does the 21 V supply pair (terminals 1 + / 2 −) read with its only load, the
factory panel, disconnected? This is the "factory panel disconnected" row of M1 in
[`../research/measurement-plan.md`](../research/measurement-plan.md). It sets the
upper end of the regulator's input range, and it was made urgent by M2a: the
earlier 22 V reading was taken with the panel's ~10 W on the rail.

## Setup

Multimeter across terminals 1 and 2 at the panel end of the cable, panel
disconnected, machine running. **Not recorded:** multimeter model and range,
machine fan speed, mains voltage at the time, whether the machine showed any
reaction to the missing panel.

## Results

| Measurement | Value | Notes |
|---|---|---|
| Terminal 1–2, factory panel disconnected | **22.8 V DC** | reported reading |
| Terminal 1–2, factory panel connected (~450 mA) | 22 V DC | from the 2026-08-21 report |
| Rise on removing the panel load | ≈ 0.8 V | derived |

## Interpretation

1. **The provisional buck stays.** TPS54202's operating maximum is 28 V. Even
   scaled for mains at +10 % (253 V), an unregulated rail at 22.8 V becomes about
   25 V — 3 V of margin, and the EN divider (100k/15k) then sits at 3.3 V against
   a 7 V absolute maximum. The MP2459 alternative is not needed.
2. **The rail is stiffer than the documents suggested.** A 0.8 V rise for a 10 W
   load step is a few percent regulation. A 14 VA transformer feeding a
   capacitor-input rectifier would move more than that. Together with M2a this
   points the same way: this machine's control supply is larger than the 14 VA
   spare-part listing, or it is not the plain rectified winding the diagrams
   show. It does not need resolving for the design; it is recorded so that nobody
   builds a budget on 14 VA.
3. **The 28.6 V estimate in protocol.md (unknown 3) is withdrawn.** It assumed a
   15 % no-load regulation that this rail does not have.

## Deviations

- Mains voltage not recorded, so the +10 % scaling above is arithmetic on a
  nominal 230 V, not a measurement at 253 V. The margin is large enough that
  this does not change the decision.
- Multimeter model still not recorded — same instrument as the M2a reading;
  one line in [README.md](README.md) when it is at hand.
- What the machine did while the panel was disconnected: **observed in passing,
  the machine appeared to keep running normally** for the duration of the
  reading (fans audibly on; the measurer's own words were "I think it continued
  normally"). Duration was short and nothing was checked deliberately, so this
  is an observation, not the item-7 test of M3 — but it is the first evidence
  on the question, and it runs against the one forum voice that said a unit with
  an SED panel "cannot be started at all" without one. The deliberate
  observation (a few minutes, then reconnect, then power-cycle with the panel
  off) stays in M3.

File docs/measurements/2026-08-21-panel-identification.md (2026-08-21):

# Target panel identified, and the bus supply measured

| | |
|---|---|
| Date | 2026-08-21 |
| Hardware revision | none — no board exists |
| Firmware version | none |
| Ambient conditions | indoor, machine running normally, not recorded further |
| Measured by | Miro Eilola |
| Report written from | photographs and a reported reading, not from witnessing the measurement |

## Question

What panel is being replaced, what is physically on its terminal block, and what
voltage does the machine actually put on the supply pair?

This is measurement M0 and the supply-voltage row of M1 in
[`../research/measurement-plan.md`](../research/measurement-plan.md). **The rest
of M1 is not answered here** — see *Still open* at the end.

## Setup

The panel was removed from its wall plate with the machine running and the wiring
left connected, and photographed front and back. The supply voltage was measured
at the terminal block with a multimeter.

**Instrument not recorded.** Multimeter make and model, and whether the reading
was taken with the panel connected or disconnected, are unknown to this report.
Both go in the next time, because a reader cannot weigh a 22 V figure without
them.

## Results

### The panel

Vallox LED control panel, front

A **Vallox DIGIT SE LED control panel** — the variant with two eight-segment LED
bar graphs and no LCD. This is the same class of panel that `pvainio/vallox-rs485`
was developed against and describes as "the one with the old led panel, no lcd
panel".

Front-panel controls, left to right along the bottom: power (its LED lit red in
the photograph), CO₂ control, %RH control, post-heating. Indicator dots along the
top: a funnel symbol, a filter-guard differential-pressure symbol, and a
heat-exchanger symbol. Right-hand half: fan speed 1…8 with left/right buttons, and
a temperature scale marked 10…27 °C with 20 °C printed at the middle, also with
left/right buttons.

At the moment of the photograph six of the eight fan-speed segments and six of the
eight temperature segments were lit. Reading a setting off a photograph is not a
measurement, so no fan speed or setpoint is claimed here.

### The terminal block

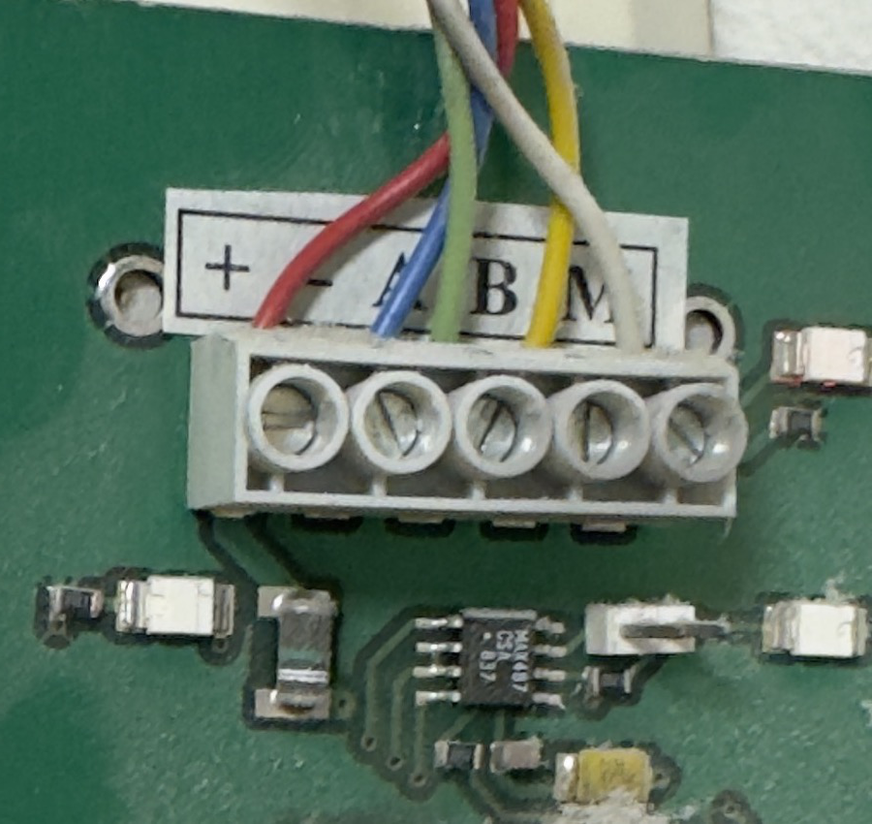
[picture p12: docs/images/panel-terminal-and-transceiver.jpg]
Panel terminal block and RS-485 transceiver


Five-pole screw terminal, silkscreen `+  −  A  B  M` reading left to right, which
matches the Vallox Digit2 SE manual exactly.

**The installed cable does not use the manufacturer's colour code.** The manual
specifies NOMAK 2×2×0.5 mm² + 0.5 mm² with orange 1 / white 1 / orange 2 /
white 2 / screen. What is actually in the terminal is a five-conductor cable:

| Terminal | Function | Wire colour as installed |
|---|---|---|
| 1 | + | red |
| 2 | − | blue |
| 3 | A | green |
| 4 | B | yellow |
| 5 | M | white |

This matters more than it looks. Every published guide for this bus describes the
wiring by colour, and in this house the colours are different. The silkscreen on
the replacement therefore has to label by **function and terminal position**, and
the installation instructions have to tell the reader to identify the terminals on
their own machine rather than trust a colour.

### Supply voltage

| Measurement | Value | Notes |
|---|---|---|
| Terminal 1 (+) to terminal 2 (−) | **22 V DC** | Reported reading. Load condition and instrument not recorded. |

Against the manufacturer's "n. 21 VDC" and one community report of 24 V, the
measured 22 V sits between them. It confirms the order of magnitude and confirms
that a design centred on 21 V nominal is not going to be surprised by this
machine. It does **not** yet give the range: no reading was taken with the panel
disconnected, or with the machine at full fan speed with heating on, and those two
are the ends the regulator has to survive.

### What the original panel does with that voltage

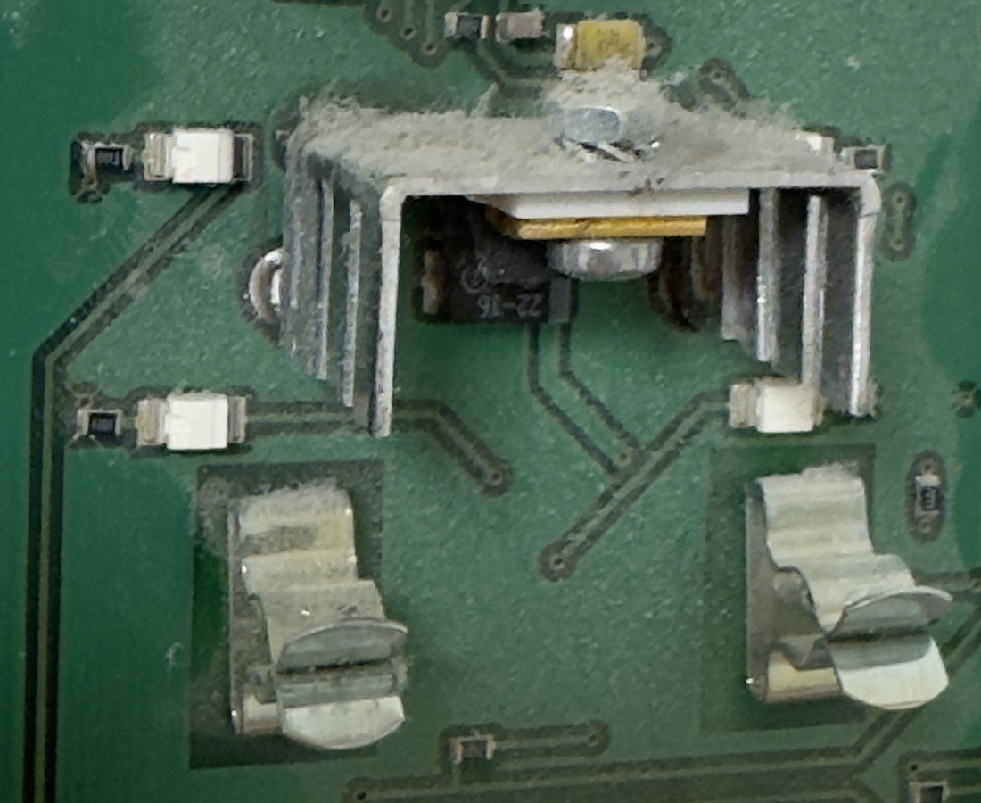
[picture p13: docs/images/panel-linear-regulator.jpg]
Linear regulator on a folded heatsink


A TO-220 regulator bolted to a folded aluminium heatsink, in the middle of the
board. That is a **linear** regulator dropping roughly 22 V to the board's logic
rail, and the heatsink says the dissipation is not trivial.

This is indirect evidence on the open question of how much current the rail can
supply, and it points the right way. A linear regulator that needs a heatsink is
burning something on the order of a watt, so the rail was designed to source at
least the panel's own draw — sixteen LEDs, a microcontroller and an RS-485
transceiver — through that drop. It is a prior, not a measurement, and M2 still
has to produce the number.

It also sets a benchmark worth publishing later: a switching regulator in the
replacement should draw **less** from the bus than the panel it replaces, while
doing more. That is a comparison this project can actually make, because the
original is here to measure.

### The bus transceiver in the original

Visible in the terminal photograph, immediately below the terminal block: a
SOIC-8 marked **MAX487 CSA .037**.

The MAX487 is a 1/4-unit-load, slew-rate-limited RS-485 transceiver: 48 kΩ
receiver input impedance, up to 128 nodes, error-free to 250 kbps. Source: the
Analog Devices MAX481/483/485/487–491/MAX1487 datasheet — quoted rather than read,
because their server could not be fetched from here. See the note in
[`../research/sources.md`](../research/sources.md).

That is a design constraint for the replacement, and a useful one:

- **Bus loading.** The machine's driver was specified against a 1/4-unit-load
  panel. The replacement should present the same load or less, so that removing
  the original and fitting this one does not change what the machine's driver
  sees.
- **Slew rate.** The original deliberately uses a slew-limited driver at 9600
  baud. Fitting a 10 Mbps part in its place would raise emissions on a cable that
  runs through a house for no benefit at all.

### Other parts identified

- PLCC-44 device, covered by a white label printed `00039C / 200298` — the panel's
  microcontroller and, judging by the label, its firmware revision. The part
  number is under the label and was not read.
- Two rows of eight LEDs, driven directly from the board.
- Two tall formed-metal parts near the middle of the board, which are the
  mechanical interface to the front assembly.

## Interpretation

1. The panel is the LED variant of the Vallox DIGIT SE, which is the best-covered
   variant in the existing open-source work. The register map compiled in
   [`../research/protocol.md`](../research/protocol.md) was largely derived from
   this same class of machine, which raises confidence in it — without making any
   of it measured.
2. The supply pair carries 22 V, consistent with the manufacturer's figure. The
   design input range still has to come from readings at both ends of the load.
3. The original panel is bus-powered through a linear regulator with a heatsink,
   which is a good sign for the replacement being bus-powered too.
4. Two requirements arrived that were not in the specification before: match or
   better the MAX487's bus loading, and keep the driver slew-rate limited.
5. The installed wire colours do not match the manufacturer's documentation, which
   changes how the installation instructions have to be written.

## Deviations

- **The measurement conditions were not recorded.** The 22 V figure has no
  instrument, no load state and no ambient temperature attached to it. It is
  recorded as reported and is enough to confirm the order of magnitude; it is not
  enough to set a regulator's input range, and it is not treated as if it were.
- The panel's LED states were photographed but are not reported as readings.
- The panel was opened with the machine energised. The bus is extra-low voltage,
  but whether it is genuinely isolated from mains has not been established, which
  is exactly the next item.

## Still open

The two rows of M1 that gate everything else are **not** answered by this report:

- Terminal 2 (−) and terminal 5 (M) to protective earth, AC and DC. Until that
  reading exists, the panel bus is treated as possibly mains-referenced.
- The supply voltage at no load and at full machine load, and its ripple.

M2, how much current the rail can supply, is also still open. The heatsink is a
hint, not a number.

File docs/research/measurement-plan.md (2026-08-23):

# Measurement plan

What has to be measured on the real machine before the schematic is drawn, in the
order it has to happen, and what result confirms or kills each claim in
[protocol.md](protocol.md).

Each step writes a report into `docs/measurements/` in the format required by the
workspace rules. A step is not done because it was attempted — it is done when its
report exists with numbers in it.

## Safety assessment

The machine is a mains appliance. Its connection box carries 230 V and, on units
with electric pre- and post-heating, up to 2.4 kW of heater load on a 16 A supply.

Rules for every step below:

1. **The machine is disconnected at the plug before any cover comes off**, and it
   stays disconnected while anything is being wired. The plug lead is 1.8 m from the
   top of the machine and is the disconnection means.
2. **Nothing is connected to the panel terminals until step M1 is complete**,
   including instruments. M1 exists to find out what those terminals actually are.
3. **The (+) terminal is treated as destructive.** The manufacturer states that
   miswiring it destroys the panel. Every connection to terminal 1 is checked twice
   against the terminal numbering before power is applied, and the first power-up of
   any new circuit happens on the bench from a current-limited supply, not on the
   machine.
4. **The house is occupied and the ventilation is in use.** Test windows are agreed
   in advance and kept short. The machine is left in a working state at the end of
   every session, verified from the factory panel, not assumed.
5. **No writes to the bus until M5.** The bus controls a real appliance. A wrong
   frame does not produce an error message, it changes what the machine does.

## M0 — Identify the machine

*No instruments. Cannot be skipped.*

Photograph the model plate, the connection box with the terminal strip visible, the
existing panel front and its terminal block with the wires still connected, and the
fan assembly. Record model, year, serial, panel model, panel address, which optional
sensors are fitted, and whether the fans are AC or DC.

**Result:** the table in [target.md](target.md) is filled in. Everything downstream
depends on it — the register set, whether 0xB0/0xB1 exist, which address is free.

## M1 — Is the panel bus safe to touch, and what is on it

*Multimeter with a CAT III rating. Machine powered.*

| Measurement | Expected | What it decides |
|---|---|---|
| Terminal 2 (−) to protective earth, AC and DC | Near 0 V AC, small DC offset | Claim 3. **If a significant AC voltage appears, the panel bus is mains-referenced and this project stops in its present form.** |
| Terminal 5 (M) to protective earth, AC and DC | Same | As above |
| Terminal 1 to terminal 2, machine idle | approx. 21 V DC, per the manual | Claim 2 vs claim 5 (24 V) |
| Same, machine at fan speed 8, heating on | Sags by some amount | Lower end of the input range |
| Same, factory panel disconnected | Rises by some amount | Upper end of the input range, no-load. **Done 2026-08-22: 22.8 V** ([report](../measurements/2026-08-22-rail-voltage-no-load.md)) — the buck stays |
| Ripple on terminal 1–2, oscilloscope, AC coupled | Unknown | Whether the supply is regulated or a rectified transformer winding |
| A and B to M, DC, bus idle | Inside −7…+12 V | Claim 4, and whether the bus is biased |
| A–B differential, bus idle | Some hundreds of mV if biased, near 0 if not | Whether this board needs fail-safe biasing |

| Terminal 2 and terminal 5 to protective earth, resistance, **machine unplugged** | Open circuit | SELV (floating) versus PELV (earthed on the mainboard). A voltage reading alone cannot tell them apart |

**This step is the gate for everything else.** No further work happens until the
first two rows are known.

*Documentary support, 2026-08-22.* Four generations of Vallox wiring diagrams —
Digit SE 12/99 (the LED-panel generation: a separate `M2 Muuntaja 230VAC/16VAC`,
secondary fused T800 mA on the mainboard), Digit2 SE 2008, 121 SE 2011
(`230VAC/16VAC`) and ValloPlus 350 SE 2015 (`Schutzspannungstransformator`) — all
draw the panel supply as a separate secondary winding, and every manual describes
panel wiring as a user-level job. The expected result of the first two rows is
therefore "near 0 V", and the reading is a check on a documented design, not a
coin toss. It is still taken first: a diagram cannot show an absent GND–PE bond.
Sources in [sources.md](sources.md), the claim in [protocol.md](protocol.md) §3.

## M2a — What the original panel draws

**Done 2026-08-22: 450 mA continuous, 700 mA momentary** —
[report](../measurements/2026-08-22-panel-current.md). Instrument, range, machine
state and the trigger of the peak are still to be recorded; the report says so.
**Do next, in the same position:** the rail voltage with the panel disconnected
(M1's no-load row) — with ~10 W removed from an unregulated secondary the rail
rises, and the provisional buck's 28 V operating maximum is what that reading is
measured against.

*Multimeter in series with the + conductor. Two minutes. Do this before the panel
comes off the wall, because afterwards it is not connected to anything.*

Break the + wire at the terminal, put the meter in series, and read the current
with the machine idle, with the machine at fan speed 8, and with the panel's own
LEDs at their brightest.

**Why this is the most valuable measurement available right now.** The panel's
logic runs from a *linear* regulator, so its input current is its output current.
Whatever it draws is current the rail has been delivering, continuously, for
twenty years. That converts the central open question of this project — how much
can the bus give — from an inference about the size of a heatsink into a number,
and it does so without loading the rail, without risking anything and without
transmitting a single frame.

**Result:** the demonstrated floor of the rail's capability, and with it the power
budget in [user-interface.md](user-interface.md) stops being arithmetic.

*What the documents already say, 2026-08-22.* The rail is an unregulated rectified
16 VAC secondary of a **14 VA** control transformer (spare part 940130), fused
**T800 mA** on the mainboard, and shared with the mainboard, its relays, the
damper motor and every bus accessory Vallox allows (3 panels, 5 CO₂, 2 RH, LON).
That is the designed ceiling for *everything*, not for one panel. On the other
side, Creating Smart Home's readers and a Helios owner have run ESP8266/ESP32
boards through a buck from this pair alongside the factory panel for years without
a reported brown-out. The target board's 3.3 V budget sits inside that envelope;
M2a still gives the number, and no document gives the panel's own draw.

## M2 — How much current can the rail give

*Bench supply not usable here — the source is the machine. Electronic load or a
resistor decade, plus a multimeter, plus the oscilloscope on the rail.*

M2a gives the floor — what the rail has been supplying. This gives the ceiling.

Load the rail in steps with the machine running, watching the rail voltage and
watching the panel for a bus fault or a reset. Find the current at which either the
rail collapses or the machine complains, and stay well below it.

**Result:** the power budget. If the usable headroom turns out to be smaller than an
ESP32-S3's Wi-Fi transmit peak plus margin, the design changes — either a large bulk
reservoir sized from the measured burst profile, or a lower-power radio choice, or
the board stops being bus-powered. This is the single number that most affects the
bill of materials, and it is not in any datasheet.

## M3 — Passive capture

*USB RS-485 adapter with the driver disabled or a receive-only adapter, connected
A/B/M only. Nothing connected to terminals 1 and 2. Logic analyser or oscilloscope
in parallel.*

The adapter must not be able to transmit. This is checked on the bench first by
connecting it to a second adapter and confirming that nothing comes out of it while
the software runs.

Capture, with the factory panel connected and operating normally:

1. Idle traffic, 30 minutes.
2. The panel's start-up burst, from machine power-on.
3. A fan speed change, each step 1→8 and back.
4. Each panel button pressed once — power, CO₂, %RH, post-heating.
5. The temperature scale moved across its full 10…27 °C range.
6. If the unit has them: a CO₂ or RH sensor exchange, looking for 0x91 / 0x8F.

Items 4 and 5 are what turn the capture into a specification. Every button on the
panel maps to a register write, and this is the only chance to see which.

7. The panel disconnected for a few minutes with the machine running, then
   reconnected, then a power cycle with the panel off: does the machine keep
   running, show a fault, or stop — and does it *start* without a panel? One
   forum voice says a unit with an SED panel "cannot be started at all" without
   it. Observed in passing on 2026-08-22 while reading the no-load rail: the
   machine appeared to keep running normally with the panel disconnected
   ([report](../measurements/2026-08-22-rail-voltage-no-load.md)). The start
   question is untouched. The replacement's installation procedure depends on
   the answer.

**Already public, 2026-08-22** (claims 22–25 in [protocol.md](protocol.md)): the
panel's steady-state poll set `A3, 29, 35, A3, 71` every ≈ 5–6 s, the mainboard's
≈ 12 s broadcast block to 0x20, and the manufacturer's 10 ms response window and
send/acknowledge rule. Items 1 and 3 above therefore confirm; items 2, 4, 5 and 7,
the acknowledge byte, and the undocumented `0x49–0x5C` broadcasts seen in one Digit
SE capture are what nobody has published.

**Verifies:** claims 1, 6, 7, 8, 9, 10, 11, 15, 22, 23, 24, 25, and which
temperature register set this machine uses. From the oscilloscope trace: the bit period, the differential
swing, the common-mode level, the rise time, and whether the idle state is properly
biased.

**This capture is also the specification for the replacement.** Because the panel
is being removed rather than joined, whatever it says on this bus is what the
replacement has to say in its place — which registers it polls, how often, and
what it writes when a button is pressed. Capture it thoroughly while it is still
on the wall, because afterwards it is a spare part in a drawer and the machine has
nothing to compare against.

**Result:** `docs/measurements/<date>-bus-capture.md` with the scope images, and a
raw capture file kept in the repository — a decoded reference capture is something
none of the existing projects publish.

The capture is analysed with [`scripts/vlx-decode`](../../scripts/vlx-decode/),
which is built from the same codec the firmware runs, so the report and the
device cannot disagree about what a telegram means. It reports the address
census, the register census, which temperature register set this machine uses,
and how many bytes it had to discard to stay in sync.

## M4 — Timing

*From the M3 captures. No new hardware.*

Measure, as distributions rather than single numbers: the gap between the last byte
of one frame and the first byte of the next; the delay from a poll to its answer;
the panel's poll period; and the longest silent gap in a 30-minute capture.

**Result:** the real value behind claim 12. The 100 ms figure in existing software is
a chosen constant, not a measurement, and this is where it gets replaced by
something with evidence behind it. It also sets the RS-485 driver-enable timing —
how long after the last stop bit the driver may stay on.

## M5 — First transmission

*Only after M1–M4 are reported. Poll frames only. A write allow-list in the software
that is empty.*

Send one poll for register 0xA3 to 0x11, from an address confirmed unused in M3.
Confirm the answer, confirm the factory panel does not report a bus fault, confirm
the machine keeps running.

Then poll each read-only register from the map and record which ones answer. A
register that does not answer on this machine is not in this machine's map, and that
is a finding worth publishing per model.

**Result:** the verified register map for this specific machine, and the answer to
whether a second client is tolerated at all.

## M6 — First write

*Only after M5. One register. Fan speed. Nothing else.*

Set fan speed to the value it already has, and confirm nothing changes. Then step it
by one and confirm the factory panel shows the same value. Then set it back.

The write allow-list in the firmware stays at exactly one register until this report
exists, and every register added to it later needs its own entry in the report.

**Result:** claim 19 is contained by construction rather than trusted.

## What is deliberately not tested

- Duplicate panel addresses, claim 13. The failure mode is a machine in a fault
  state and there is nothing to learn from it.
- Writing any register whose meaning is only supported by a single source.
- Anything on the mains side of the machine.
- Long-term behaviour of anything, at this stage. That belongs to bringup.

## Instruments

To be recorded in `docs/measurements/README.md` with model numbers before the first
report is written. A measurement whose instrument is unnamed cannot be judged by a
reader, so this list is part of the evidence, not paperwork.

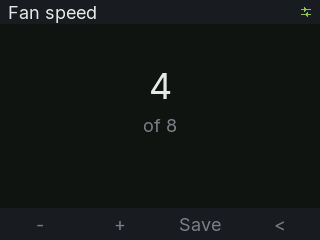
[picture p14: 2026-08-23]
firmware/test/host/golden/editor.png

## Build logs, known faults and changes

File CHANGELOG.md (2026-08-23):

# Changelog

All notable changes to this project are documented here.
Format follows [Keep a Changelog](https://keepachangelog.com/en/1.1.0/).

Hardware, firmware and enclosure are versioned separately; each release states which
combination is known to work together.

## [Unreleased]

### Added
- Initial project structure.
- Research: Vallox DIGIT RS-485 protocol and register map compiled from the
  manufacturer's Digit2 SE manual and four independent implementations, with a
  confidence rating on every claim.
- Research: panel connector pinout and wire colours from the manufacturer's manual,
  measurement plan M0-M6, risk register, and component candidates costed against
  live JLCPCB stock.
- Firmware: `vallox_protocol` codec — frame encode and decode, resynchronising
  byte-stream parser, NTC temperature table, fan speed and humidity encodings, a
  write allow-list, and a bus survey. 1420 host-side assertions, no hardware
  required.
- ESPHome: wrapper rebuilt on the shared codec, listening only.
- Tools: `scripts/vlx-decode`, a capture analyser built from the same codec as
  the firmware. Decodes telegrams into engineering units and reports the address
  and register census, which temperature register set a machine uses, and who is
  on the panel side of the bus.
- Security position written before the firmware: threat model, OTA and rollback,
  signed images, and the reasoning for leaving secure boot and flash encryption
  off in the published build.
- First measurement report: the target panel identified as a Vallox DIGIT SE LED
  panel with photographs, its terminal block, its MAX487 transceiver and its
  linear supply, and 22 V measured on the supply pair.
- Local interface analysis: LED bar against mono OLED against colour TFT, costed
  against live stock, with the power arithmetic, the OLED burn-in question, the
  legibility arithmetic and a recommendation. Lands on a 2.0" 320x240 colour IPS,
  three buttons and three indicator LEDs. A 0.96" OLED was the first answer and was
  revised: it shows eight characters by three lines at arm's length, which is a
  readout rather than the menu the display was chosen to provide, and colour TFT
  costs three to five times less per square millimetre than mono OLED.
- Buttons chosen rather than carried: four tactile switches on a resistor ladder
  into one ADC pin, because the display, bus and indicators leave ESP32-C3-MINI-1
  with thirteen usable pins and four discrete button GPIOs do not fit. Capacitive
  touch rejected (C3 has no touch peripheral, and a no-feedback control should not
  be the only way to run a household's ventilation); rotary encoder rejected on
  cost and wear.
- Measurement M2a: put an ammeter in series with the original panel's supply wire
  before removing it. Because that panel's regulator is linear, its input current
  is the rail's demonstrated capability — the cheapest available answer to the
  project's central open question.
- Firmware: `vallox_machine`, a host-side emulator of the Vallox mainboard —
  register table, poll and write handling, temperature physics and periodic
  broadcasts — plus `panel_hal.h`, the contract the panel UI sees on the device,
  in host tests and in the browser, and a host memory bus so both sides of the
  simulated link run in the same process (PR #11, PR #12).
- Firmware: `panel_ui`, the panel's UI core — pre-rendered Inter fonts and a
  dirty-rectangle renderer, English/Finnish texts behind one key enum, button
  ladder decoding with debounce and repeat, `vlx_client` (shadow register map,
  poll scheduler, write with acknowledge, bus fault), a data-driven page engine
  (dashboard, lists, editors, status), five golden images covering the main
  screens, and `panel_host`, a command-line runner that renders any state to a
  PNG.

### Changed
- **Scope: this replaces the original panel instead of joining the bus alongside
  it.** Testing on the target machine shows two controllers override each other,
  so coexistence is not available. The device is now load bearing, everything the
  panel could set has to be settable here, and whether it needs local controls is
  an open design decision.
- Transceiver chosen against the part it replaces: the original panel uses a
  MAX487, 1/4 unit load and slew-rate limited, so the replacement uses a 1/8 unit
  load slew-limited part with integrated fail-safe rather than the cheapest one.
- The bus survey in the firmware verifies that the panel side is silent before
  transmitting, instead of picking a free address.
- Hardware CI skips ERC and DRC until a KiCad project exists, instead of failing.

### Fixed
- The worked example in the circulated protocol documentation states the checksum
  of `01 21 11 00 A3` as `C9`. It is `D6`. Found by a unit test.

### Compatibility

| Release | Hardware | Firmware | Enclosure |
|---|---|---|---|
| — | — | — | — |

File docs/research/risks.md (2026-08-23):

# Risks

What can stop this project, how likely it is, and what the way around it is. Ordered
by how much damage the risk does if it lands, not by probability.

## R1 — The panel bus is not isolated from mains

**If true:** the project stops in its present form. A device that a user wires
themselves cannot sit on a mains-referenced bus and also expose a network interface.

**Evidence either way:** four generations of Vallox wiring diagrams (Digit SE
12/99, Digit2 SE 2008, 121 SE 2011, ValloPlus 350 SE 2015), read 2026-08-22 as the
vector drawings they are, draw the panel supply as a separate 230 V / 16 VAC
secondary and name it a protective-voltage winding; the 1999 guide for the LED-panel
generation uses a physically separate control transformer. Every manual describes
panel wiring as a user-level job. No community report of an earth-referenced
adapter being damaged was found. What no document can show is a GND–PE bond on the
mainboard (PELV), which is what the measurement is now for.

**Way around:** measurement M1, before anything is connected. If it turns out to be
mains-referenced, the honest outcome is to publish that finding — it is more useful
to the community than a device would have been — and to redesign around a fully
isolated front end with an external supply.

**Status:** open as a check, no longer as a coin toss. Measurement M1 (voltage
and, unplugged, resistance to PE) stays first.

## R2 — The 21 V rail cannot power a Wi-Fi radio

**If true:** the board cannot be bus-powered, which removes most of what makes it
better than the existing breadboard solutions.

**Why it is plausible:** the rail was specified to run a panel with an LCD and a
keypad, plus up to five CO₂ sensors and two humidity sensors in the worst case. No
document states a current limit for the rail itself, but (2026-08-22) the control
transformer is a 14 VA part and its secondary is fused T800 mA, shared with the
mainboard, relays and damper motor — so the whole low-voltage side has well under
0.65 A at 21 V to share. An ESP32 transmitting draws a few hundred milliamps at
3.3 V in bursts, which is tens of milliamps at the rail; others have run exactly
that from this pair alongside the factory panel for years.

**Ways around, in order of preference:**

1. Size a bulk reservoir from the measured burst profile so the average draw is what
   the rail sees, not the peak. This is the normal answer and it is cheap.
2. Reduce the radio duty cycle: longer Wi-Fi listen intervals, no mDNS chatter.
3. Drop to a lower-power radio. This is a real option and it changes the MCU choice.
4. Accept an external supply. This is the outcome that makes the board ordinary, so
   it is last.

**Status:** closed for design purposes 2026-08-22 — M2a measured the factory
panel at 450 mA continuous / 700 mA momentary, two to four times what this board
needs at the rail ([report](../measurements/2026-08-22-panel-current.md)).
Conditions still to be recorded; M2 (loading the rail beyond the panel) is no
longer needed to decide whether the board can be bus-powered.

## R3 — Writing the wrong register damages the machine

**If true:** an expensive appliance in a house that needs ventilation.

**Way around, by construction rather than by care:**

- The firmware carries an explicit allow-list of writable registers. It starts with
  one entry. A register joins the list only when a measurement report exists for it.
- Every write is preceded by a read of the same register, and followed by a read
  back. A write that does not read back is an error, not a retry.
- Values are range-checked against the encoding, not just passed through. A fan
  speed that is not one of the eight thermometer codes never reaches the bus.
- Bit registers are read-modify-write against a fresh read, never against a cached
  value.

**Status:** contained by design. Confirmed at measurement M6.

## R4 — Reversed wiring destroys the board

**If true:** a user builds the device, wires it the way the cable happens to fall,
and it dies — which is exactly what the manufacturer warns happens to the factory
panel.

**Way around:** this is a design requirement, not a risk to be accepted. The 21 V
input survives reversed polarity, and the A/B pair survives being swapped without
damage — swapped data just means it does not communicate. Both are tested on the
bench before the board is ever connected to a machine, and the test goes into
`docs/measurements/`.

The board should also make the mistake hard: terminals labelled on the silkscreen in
the manufacturer's own order and with the manufacturer's own wire colours, so the
label matches the cable in front of the installer rather than a datasheet.

**Status:** design requirement, not open.

## R5 — The register map is model-specific

**If true:** the project works on one machine and produces wrong readings or wrong
behaviour on another, which is worse than not supporting it.

**Evidence:** already known to be true in part. Vallox 130 D is documented by
Tom-Bom-badil as needing different register numbers, and pvainio handles two
different temperature register sets and calls one of them "the newer protocol".

**Way around:**

- Scope the claim honestly: the README says which machine it was verified on and
  which registers answered, and nothing more. This is the kind of limitation that
  makes a reference project credible rather than weak.
- Make the firmware discover rather than assume: poll the map at start-up, record
  which registers answer, and publish only those.
- Provide a way for a user with a different model to produce a capture and send it
  back, and add per-model findings to the repository as they arrive.

**Status:** open, managed by scope rather than solved.

## R6 — A second client on the bus is not tolerated — CONFIRMED TRUE

**Established.** Prior testing on the target machine: with two controllers on the
bus, they override each other. The manufacturer's "up to three panels" applies to
three Vallox panels, which the mainboard keeps in step by broadcasting state to
the whole panel group. A client that polls on its own schedule is not part of that.

**Consequence:** the product changed. It is now a panel replacement, not an
addition. The decision record is in
[`../../hardware/docs/decisions.md`](../../hardware/docs/decisions.md).

**Status:** closed, and it created R10 and R11 below.

## R10 — The device is now load bearing

**If it fails:** nothing controls the ventilation. The machine keeps running at
whatever it was last told, which is the difference between an inconvenience and a
hazard — but nobody can change it until the device is fixed.

This risk did not exist in the previous design. It arrived with R6 and it is the
price of the only architecture the bus allows.

**Way around:**

- Local controls on the device, so that a network outage is not a loss of control.
  Analysed in [user-interface.md](user-interface.md); the answer is a sleeping
  0.96" OLED, three buttons and three always-on indicator LEDs, which also covers
  the setpoints the old panel could reach — see R11.
- The machine's own protections — frost protection, over-temperature thermostats,
  the defrost cycle — live in the machine's firmware and this device cannot reach
  them. Nothing this device does or fails to do turns into a safety problem, and
  the README should say so plainly rather than leaving a reader to wonder.
- A watchdog and a rollback on failed OTA, so that a bad update does not leave a
  wall panel dead. Already in [../security.md](../security.md).
- Keep the original panel. It is being removed, not destroyed, and a working
  spare in a drawer is the cheapest possible recovery path.

**Status:** open. The local-interface half of it is answered in
[user-interface.md](user-interface.md); the rest — watchdog, OTA rollback, keeping
the old panel as a spare — is firmware and process work that has not started.

## R11 — Every setting the panel could reach has to be reachable here

**If missed:** the household quietly loses the ability to set the heating
setpoint, the bypass temperature or the fan speed limits, and nobody finds out
until the season changes.

**Way around:** the register list in [protocol.md](protocol.md) is the checklist,
and each writable register joins the firmware's allow-list only with a measurement
report behind it. The gap between "what the panel could do" and "what the
replacement can do" is tracked explicitly rather than discovered later.

**Status:** open, and it conflicts productively with R3: R3 wants the write list
short, R11 wants it complete. The resolution is that it grows one measured
register at a time, never one guessed register at a time.

## R7 — Components are not available when the board is ordered

**If true:** a redesign at fabrication time, which is the most expensive place to
find out.

**Way around:** the parts are chosen against live stock at the fab before the
schematic is frozen, preference given to Basic/preferred parts in the assembler's own
inventory, and the stock check is repeated as a gate immediately before ordering
rather than trusted from the time of selection. Second sources are recorded for
every part that is not a commodity passive.

**Status:** managed. See [component-candidates.md](component-candidates.md).

## R8 — Warranty and liability

Modifying the machine, or connecting anything to its bus, voids the manufacturer's
warranty and is the user's decision. The README says so plainly, in its own section,
not in a footnote. The project makes no safety claim and no IP rating claim that has
not been tested.

The machine is a ventilation appliance in a home. A failure of this board must leave
the machine running as it was — the device is an observer and an occasional
commander, never something the machine depends on.

**Status:** documentation requirement.

## R9 — Testing happens in an occupied house

**If true:** somebody's ventilation is off for an afternoon, in the worst case in
winter.

**Way around:** short agreed test windows, the machine returned to a verified working
state at the end of every session, and no long unattended runs until the bench work
is finished.

**Status:** managed by process. See [measurement-plan.md](measurement-plan.md).

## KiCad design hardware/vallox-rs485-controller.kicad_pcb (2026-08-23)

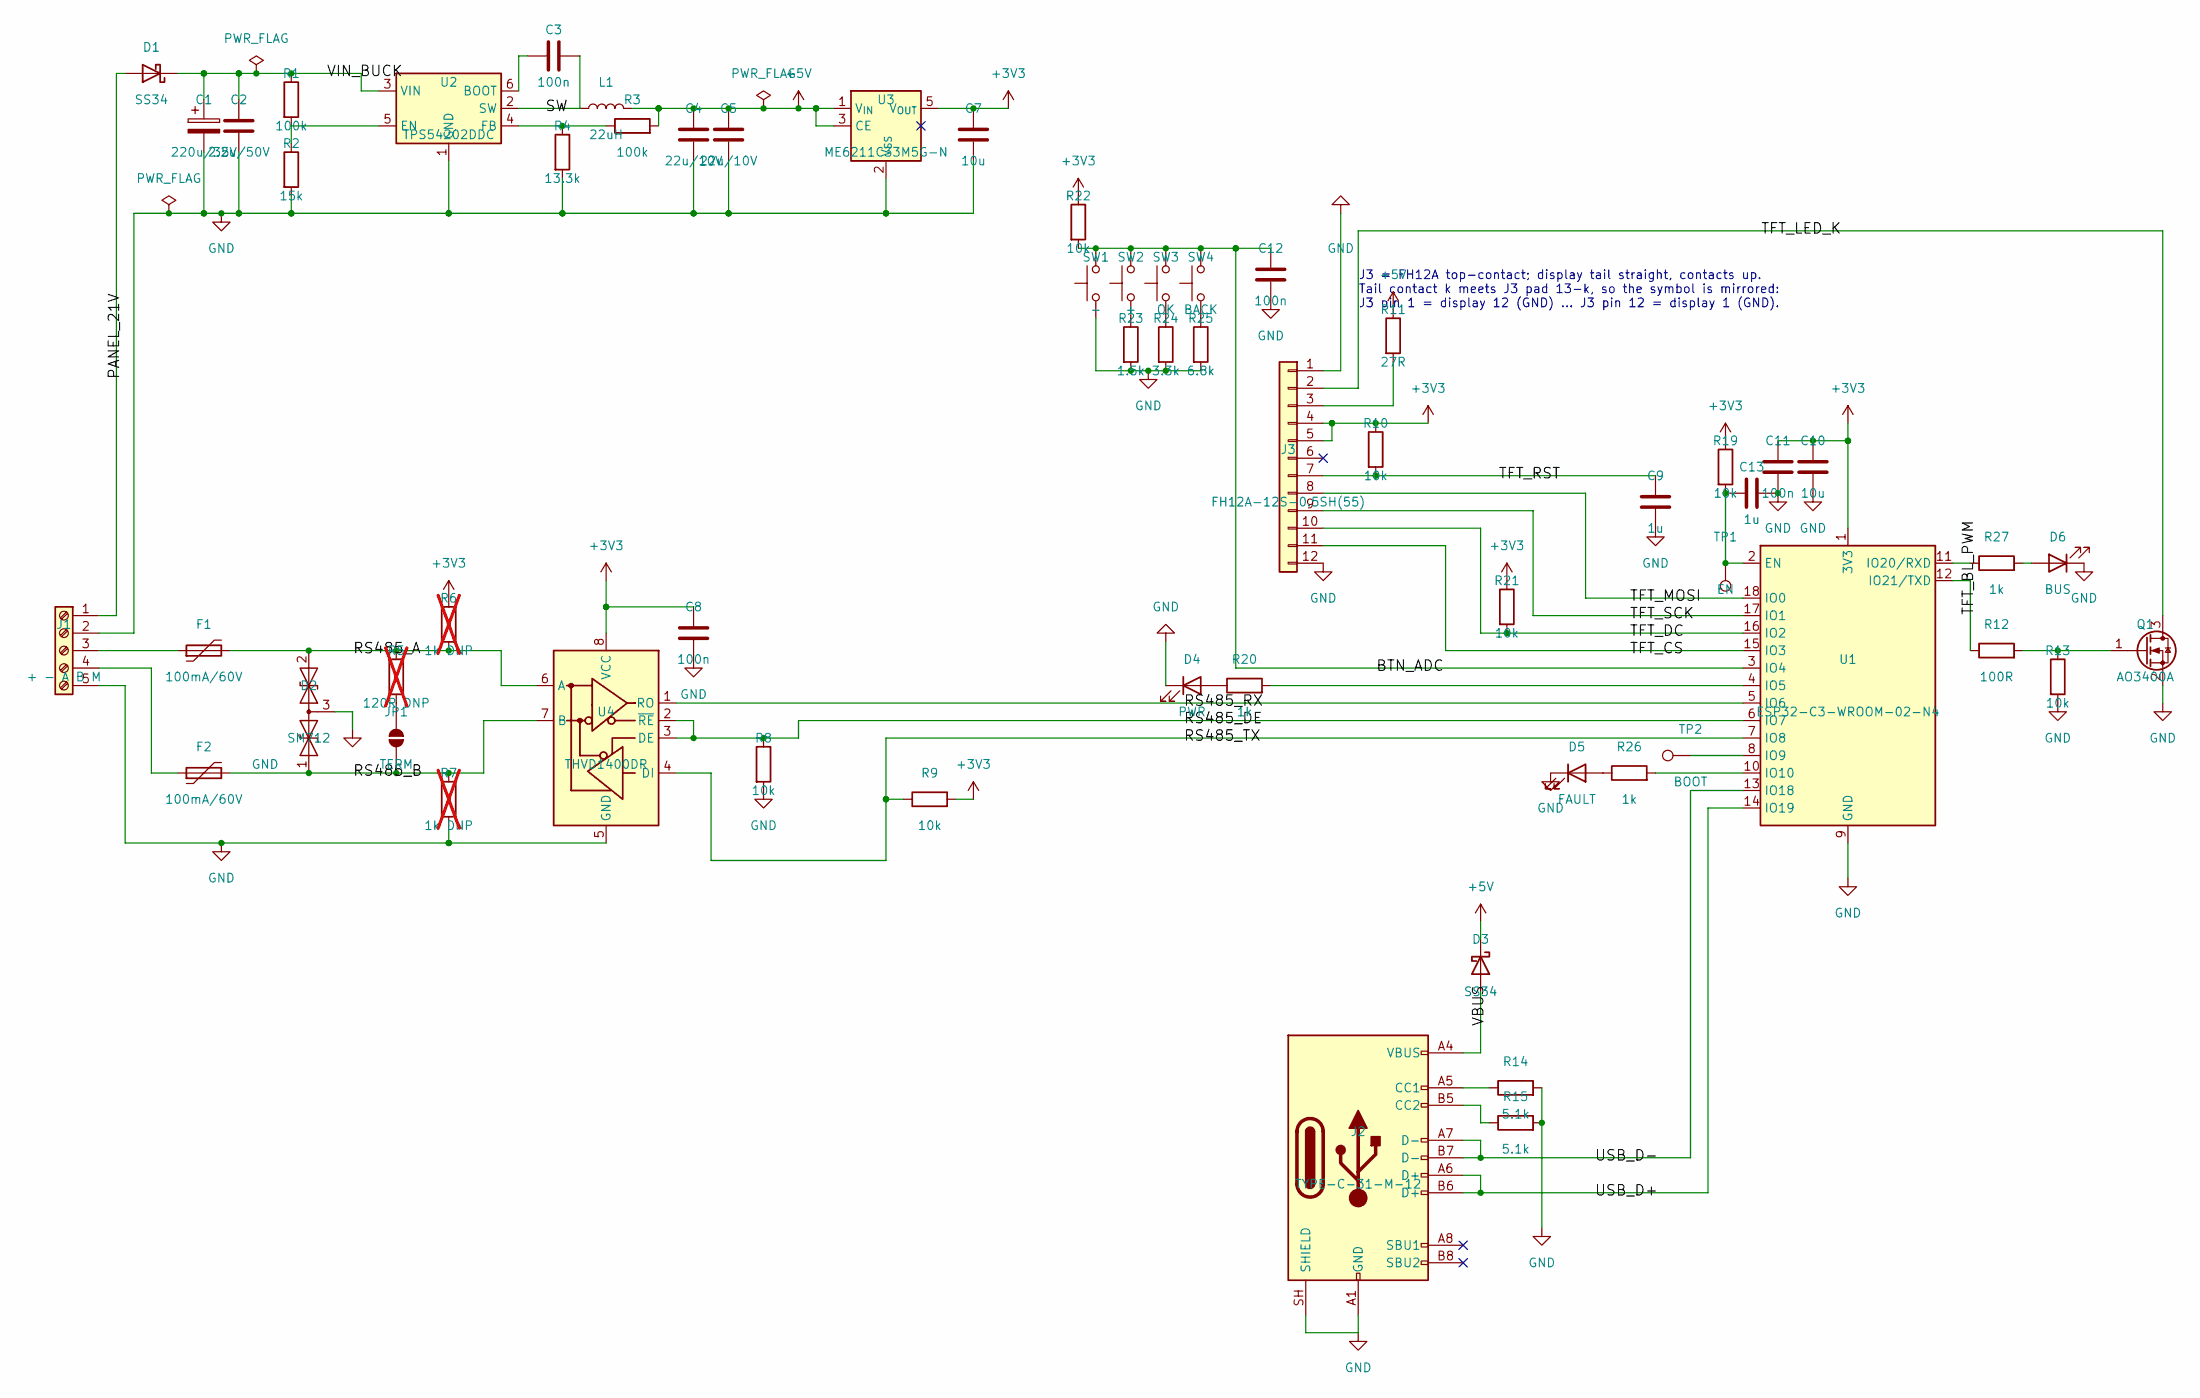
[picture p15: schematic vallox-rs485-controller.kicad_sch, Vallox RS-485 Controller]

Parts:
C1: 220u/35V; CP_Elec_8x10.5; MPN UCD1V221MNL1GS; LCSC C136294
C2: 2.2u/50V; C_0805_2012Metric; MPN CL21A225KBQNNNE; LCSC C377773
C3, C8, C11, C12: 100n; C_0603_1608Metric; MPN CC0603KRX7R9BB104; LCSC C14663
C4, C5: 22u/10V; C_0805_2012Metric; MPN CL21A226MAQNNNE; LCSC C45783
C7, C10: 10u; C_0603_1608Metric; MPN CL10A106KP8NNNC; LCSC C19702
C9, C13: 1u; C_0603_1608Metric; MPN CL10A105KB8NNNC; LCSC C15849
D1, D3: SS34; D_SMA; MPN SS34; LCSC C8678
D2: SM712; SOT-23; MPN PSM712-LF-T7; LCSC C32677
D4: PWR; LED_0603_1608Metric; MPN XL-1608SYGC-06; LCSC C965805
D5: FAULT; LED_0603_1608Metric; MPN KT-0603R; LCSC C2286
D6: BUS; LED_0603_1608Metric; MPN NCD0603Y1; LCSC C84268
F1, F2: 100mA/60V; Fuse_1812_4532Metric; MPN JK-mSMD010-60; LCSC C1884489
J1: + - A B M; TerminalBlock_Phoenix_MKDS-1,5-5-5.08_1x05_P5.08mm_Horizont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; MPN DB128V-5.08-5P-GN-S; LCSC C2927513
J2: TYPE-C-31-M-12; USB_C_Receptacle_HRO_TYPE-C-31-M-12; MPN TYPE-C-31-M-12; LCSC C165948
J3: FH12A-12S-0.5SH(55); Hirose_FH12-12S-0.5SH_1x12-1MP_P0.50mm_Horizontal; MPN FH12A-12S-0.5SH(55); LCSC C596811
JP1: TERM; SolderJumper-2_P1.3mm_Open_RoundedPad1.0x1.5mm
L1: 22uH; L_Changjiang_FNR6045S; MPN FNR6045S220MT; LCSC C168080
Q1: AO3400A; SOT-23; MPN AO3400A; LCSC C20917
R1, R3: 100k; R_0603_1608Metric; MPN 0603WAF1003T5E; LCSC C25803
R2: 15k; R_0603_1608Metric; MPN 0603WAF1502T5E; LCSC C22809
R4: 13.3k; R_0603_1608Metric; MPN 0603WAF1332T5E; LCSC C25952
R5: 120R DNP; R_0603_1608Metric; MPN 0603WAF1200T5E; LCSC C22787; not fitted
R6, R7: 1k DNP; R_0603_1608Metric; MPN 0603WAF1001T5E; LCSC C21190; not fitted
R8, R9, R10, R13, R19, R21, R22: 10k; R_0603_1608Metric; MPN 0603WAF1002T5E; LCSC C25804
R11: 27R; R_1206_3216Metric; MPN 1206W4F270JT5E; LCSC C17946
R12: 100R; R_0603_1608Metric; MPN 0603WAF1000T5E; LCSC C22775
R14, R15: 5.1k; R_0603_1608Metric; MPN 0603WAF5101T5E; LCSC C23186
R20, R26, R27: 1k; R_0603_1608Metric; MPN 0603WAF1001T5E; LCSC C21190
R23: 1.5k; R_0603_1608Metric; MPN 0603WAF1501T5E; LCSC C22843
R24: 3.3k; R_0603_1608Metric; MPN 0603WAF3301T5E; LCSC C22978
R25: 6.8k; R_0603_1608Metric; MPN 0603WAF6801T5E; LCSC C23212
SW1: -; SW_SPST_PTS645Sx43SMTR92; MPN PTS645SM43SMTR92LFS; LCSC C221880
SW2: +; SW_SPST_PTS645Sx43SMTR92; MPN PTS645SM43SMTR92LFS; LCSC C221880
SW3: OK; SW_SPST_PTS645Sx43SMTR92; MPN PTS645SM43SMTR92LFS; LCSC C221880
SW4: BACK; SW_SPST_PTS645Sx43SMTR92; MPN PTS645SM43SMTR92LFS; LCSC C221880
TP1: EN; TestPoint_Pad_1.0x1.0mm
TP2: BOOT; TestPoint_Pad_1.0x1.0mm
U1: ESP32-C3-WROOM-02-N4; ESP32-C3-WROOM-02; MPN ESP32-C3-WROOM-02-N4; LCSC C2934560
U2: TPS54202DDC; SOT-23-6; MPN TPS54202DDCR; LCSC C191884
U3: ME6211C33M5G-N; SOT-23-5; MPN ME6211C33M5G-N; LCSC C82942
U4: THVD1400DR; SOIC-8_3.9x4.9mm_P1.27mm; MPN THVD1400DR; LCSC C3235232

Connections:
+3V3: C7.1, C8.1, C10.1, C11.1, J3.4, J3.5, R6.1, R9.2, R10.1, R19.1, R21.1, R22.1, U1.1 (3V3), U3.5 (V_{OUT}), U4.8 (VCC)
/BTN_ADC: C12.1, R22.2, SW1.2, SW2.2, SW3.2, SW4.2, U1.3 (IO4)
/PANEL_21V: D1.2 (A), J1.1
/RS485_A: D2.2 (A2), F1.2, R5.1, R6.2, U4.6 (A)
/RS485_B: D2.1 (A1), F2.2, JP1.1 (A), R7.1, U4.7 (B)
/RS485_DE: R8.1, U1.6 (IO7), U4.2 (~RE), U4.3 (DE)
/RS485_RX: U1.5 (IO6), U4.1 (RO)
/RS485_TX: R9.1, U1.7 (IO8), U4.4 (DI)
/SW: C3.2, L1.1, U2.2 (SW)
/TFT_BL_PWM: R12.1, U1.12 (IO21/TXD)
/TFT_CS: J3.11, U1.15 (IO3)
/TFT_DC: J3.10, R21.2, U1.16 (IO2)
/TFT_LED_K: J3.2, Q1.3 (D)
/TFT_MOSI: J3.8, U1.18 (IO0)
/TFT_RST: C9.1, J3.7, R10.2
/TFT_SCK: J3.9, U1.17 (IO1)
/USB_D+: J2.A6 (D+), J2.B6 (D+), U1.14 (IO19)
/USB_D-: J2.A7 (D-), J2.B7 (D-), U1.13 (IO18)
/VBUS: D3.2 (A), J2.A4 (VBUS), J2.A9 (VBUS), J2.B4 (VBUS), J2.B9 (VBUS)
unnamed: D4.2 (A), R20.1
unnamed: D5.2 (A), R26.1
unnamed: D6.2 (A), R27.2
unnamed: F1.1, J1.3
unnamed: F2.1, J1.4
unnamed: J2.A5 (CC1), R14.1
unnamed: J2.B5 (CC2), R15.1
unnamed: J3.3, R11.2
unnamed: JP1.2 (B), R5.2
unnamed: Q1.1 (G), R12.2, R13.1
unnamed: R23.1, SW2.1
unnamed: R24.1, SW3.1
unnamed: R25.1, SW4.1
unnamed: C13.1, R19.2, TP1.1, U1.2 (EN)
unnamed: R20.2, U1.4 (IO5)
unnamed: TP2.1, U1.8 (IO9)
unnamed: R26.2, U1.10 (IO10)
unnamed: R27.1, U1.11 (IO20/RXD)
unnamed: C3.1, U2.6 (BOOT)
unnamed: R1.2, R2.1, U2.5 (EN)
unnamed: R3.1, R4.1, U2.4 (FB)

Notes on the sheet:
J3 = FH12A top-contact; display tail straight, contacts up. Tail contact k meets J3 pad 13-k, so the symbol is mirrored: J3 pin 1 = display 12 (GND) ... J3 pin 12 = display 1 (GND).

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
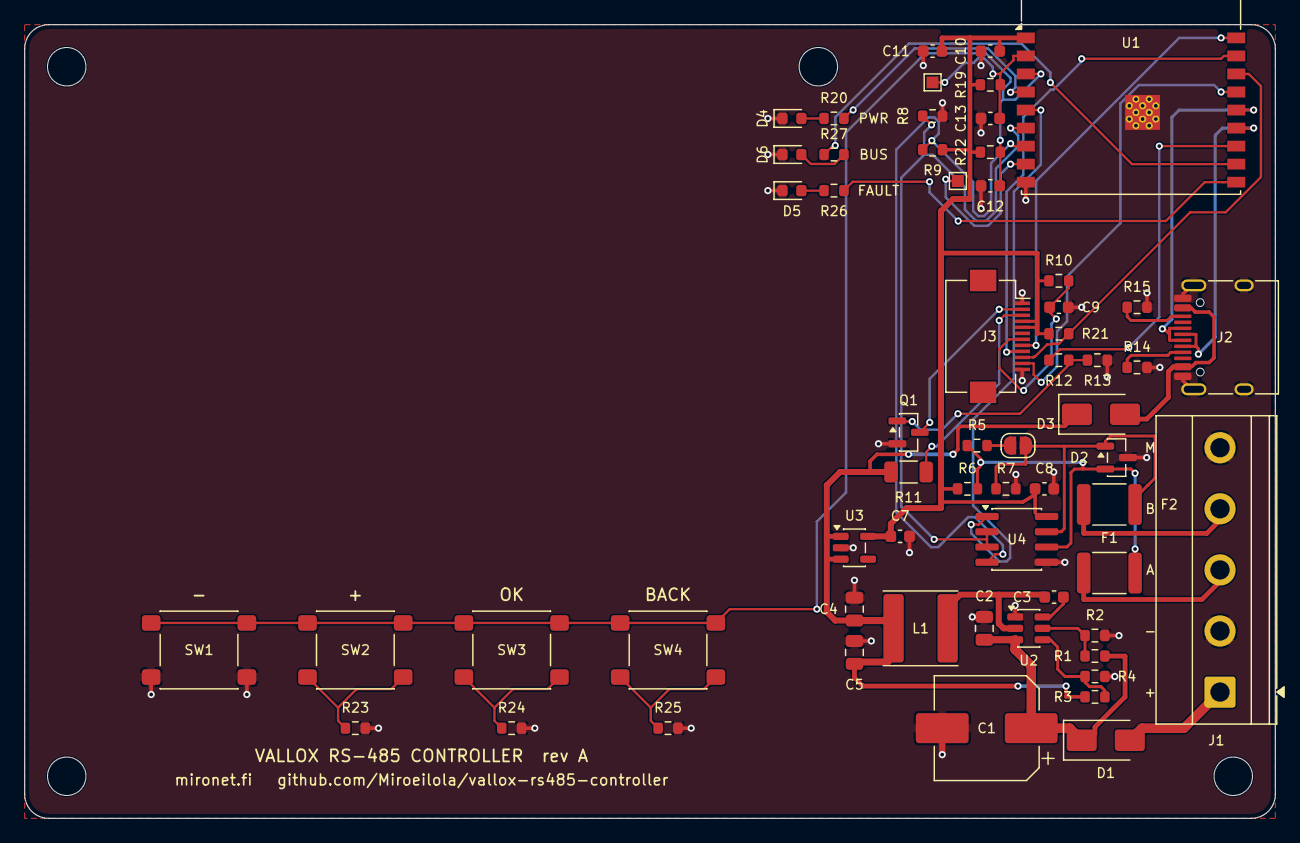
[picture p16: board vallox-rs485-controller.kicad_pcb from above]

Board: 2 copper layers, 104.0 x 66.0 mm, 65 parts (0 on the bottom side), 43 nets.

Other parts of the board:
DS1: HS20HS072RX; LCD_2.0in_HSD_HS20HS072RX_FPC-12P-0.5mm
H1, H2, H3, H4: M3; MountingHole_3.2mm_M3

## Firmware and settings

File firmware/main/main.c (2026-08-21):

// SPDX-License-Identifier: MIT
// SPDX-FileCopyrightText: 2026 Miro Eilola / Mironet
//
// Vallox RS-485 Controller — application entry point.
//
// The application layer owns transports (UART, Wi-Fi, MQTT) and lifecycle.
// Protocol logic lives in components/vallox_protocol and stays free of IDF
// dependencies so it can be unit tested on the host — see firmware/test/host.
//
// There is deliberately no UART task here yet. No board exists, the bus has not
// been captured, and the electrical parameters that decide the pin assignment
// and the driver-enable timing are open measurements — see
// docs/research/measurement-plan.md. Writing a transport against guessed timing
// would only have to be rewritten once the capture exists.

#include <stdio.h>
#include <string.h>

#include "esp_app_desc.h"
#include "esp_log.h"
#include "esp_system.h"
#include "nvs_flash.h"

#include "vallox_protocol.h"

static const char *TAG = "app";

static vlx_bus_survey_t s_survey;

static void on_frame(const vlx_frame_t *f, void *ctx)
{
    (void)ctx;

    // A six-byte frame has no start delimiter, so a checksum can pass at the
    // wrong alignment. Anything that fails the address sanity check is treated
    // as noise rather than as data.
    if (!vlx_frame_is_plausible(f)) {
        ESP_LOGD(TAG, "implausible frame %02x->%02x reg %02x", f->sender,
                 f->receiver, f->reg);
        return;
    }

    vlx_bus_survey_observe(&s_survey, f);
    ESP_LOGI(TAG, "%02x -> %02x  reg %02x = %02x", f->sender, f->receiver,
             f->reg, f->value);
}

// First thing anyone needs in the field: what is running and why did it restart.
static void log_identity(void)
{
    ESP_LOGI(TAG, "%s firmware %s, reset reason %d, free heap %lu",
             "Vallox RS-485 Controller", FW_VERSION, (int)esp_reset_reason(),
             (unsigned long)esp_get_free_heap_size());
}

void app_main(void)
{
    esp_err_t err = nvs_flash_init();
    if (err == ESP_ERR_NVS_NO_FREE_PAGES || err == ESP_ERR_NVS_NEW_VERSION_FOUND) {
        ESP_ERROR_CHECK(nvs_flash_erase());
        err = nvs_flash_init();
    }
    ESP_ERROR_CHECK(err);

    log_identity();

    vlx_bus_survey_init(&s_survey);

    static vlx_parser_t parser;
    vlx_parser_init(&parser, on_frame, NULL);

    // Next, once measurements M1-M4 exist: a UART task in
    // UART_MODE_RS485_HALF_DUPLEX feeding vlx_parser_feed_buffer() and calling
    // vlx_parser_reset() on each idle gap.
    //
    // Before that task is allowed to transmit anything, it listens. This device
    // takes the original panel's place on the bus, and two controllers on this
    // bus override each other - so vlx_bus_survey_other_controller() returning
    // non-zero after the listening window means the old panel is still
    // connected, and the correct response is to stay silent and say so, not to
    // start talking anyway.
}

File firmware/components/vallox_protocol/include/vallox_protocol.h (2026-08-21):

// SPDX-License-Identifier: MIT
// SPDX-FileCopyrightText: 2026 Miro Eilola / Mironet
//
// Vallox DIGIT RS-485 protocol codec.
//
// Free of ESP-IDF headers on purpose: the same source is compiled by the
// firmware, by the ESPHome component and by the host test runner. Nothing here
// touches a UART, a clock or the network — that belongs to the layer above.
//
// The protocol is 9600 8N1 half duplex. Every telegram is six bytes:
//
//   +--------+--------+----------+----------+--------+----------+
//   | domain | sender | receiver | register | value  | checksum |
//   +--------+--------+----------+----------+--------+----------+
//      0x01                                            low byte of sum of 0..4
//
// A poll sets register = 0x00 and puts the wanted register number in value.
// A write, and the answer to a poll, put the register number in register and
// its contents in value.
//
// Every register number and encoding in this file is compiled from four
// independent implementations and the Vallox Digit2 SE manual, and none of it
// has been verified against a machine yet. See docs/research/protocol.md for
// the confidence rating of each claim. Treat this header as a hypothesis with
// tests, not as a specification.

#ifndef VALLOX_PROTOCOL_H
#define VALLOX_PROTOCOL_H

#include <stdbool.h>
#include <stddef.h>
#include <stdint.h>

#ifdef __cplusplus
extern "C" {
#endif

#define VLX_FRAME_LEN   6u
#define VLX_DOMAIN      0x01u
#define VLX_POLL        0x00u   // register field value that marks a read request

// ---------------------------------------------------------------------------
// Addresses
// ---------------------------------------------------------------------------

#define VLX_ADDR_MAINBOARDS   0x10u  // broadcast to every mainboard
#define VLX_ADDR_MAINBOARD_1  0x11u  // the machine
#define VLX_ADDR_PANELS       0x20u  // broadcast to every panel
#define VLX_ADDR_PANEL_FIRST  0x21u
#define VLX_ADDR_PANEL_LAST   0x29u
#define VLX_ADDR_LON          0x28u  // the optional LON gateway module

// This device replaces the panel rather than joining it, so it takes the address
// the panel had. The manufacturer's commissioning procedure ends with a single
// panel at address 1, which is 0x21 on the wire.
#define VLX_ADDR_PANEL_DEFAULT VLX_ADDR_PANEL_FIRST

// ---------------------------------------------------------------------------
// Registers. Grouped as in docs/research/protocol.md.
// ---------------------------------------------------------------------------

// Measurements, read only
#define VLX_REG_IO_FAN_RELAYS       0x06u  // bit image of the eight speed relays
#define VLX_REG_IO_MULTI_1          0x07u
#define VLX_REG_IO_MULTI_2          0x08u
#define VLX_REG_FAN_SPEED           0x29u
#define VLX_REG_RH_HIGHEST          0x2Au
#define VLX_REG_CO2_HIGH            0x2Bu
#define VLX_REG_CO2_LOW             0x2Cu
#define VLX_REG_CO2_SENSORS_FITTED  0x2Du
#define VLX_REG_CURRENT_MA          0x2Eu
#define VLX_REG_RH_SENSOR_1         0x2Fu
#define VLX_REG_RH_SENSOR_2         0x30u
#define VLX_REG_TEMP_OUTDOOR        0x32u
#define VLX_REG_TEMP_EXHAUST        0x33u
#define VLX_REG_TEMP_EXTRACT        0x34u
#define VLX_REG_TEMP_SUPPLY         0x35u
#define VLX_REG_FAULT               0x36u
#define VLX_REG_POST_HEAT_ON_CNT    0x55u
#define VLX_REG_POST_HEAT_OFF_CNT   0x56u
#define VLX_REG_POST_HEAT_TARGET    0x57u

// Older machines are reported to broadcast temperatures here instead. Which set
// a given machine uses is discovered from its traffic, never assumed.
#define VLX_REG_TEMP_OUTDOOR_LEGACY 0x58u
#define VLX_REG_TEMP_EXTRACT_LEGACY 0x5Au
#define VLX_REG_TEMP_SUPPLY_LEGACY  0x5Bu
#define VLX_REG_TEMP_EXHAUST_LEGACY 0x5Cu

// Flag registers
#define VLX_REG_FLAGS_1             0x6Cu
#define VLX_REG_FLAGS_2             0x6Du
#define VLX_REG_FLAGS_3             0x6Eu
#define VLX_REG_FLAGS_4             0x6Fu
#define VLX_REG_FLAGS_5             0x70u
#define VLX_REG_FLAGS_6             0x71u
#define VLX_REG_BOOST_MINUTES       0x79u

// Bus control, broadcast twice around a CO2 sensor exchange
#define VLX_REG_RESUME              0x8Fu
#define VLX_REG_SUSPEND             0x91u

// Settings
#define VLX_REG_STATUS              0xA3u
#define VLX_REG_HEAT_SETPOINT       0xA4u
#define VLX_REG_FAN_SPEED_MAX       0xA5u
#define VLX_REG_SERVICE_INTERVAL    0xA6u
#define VLX_REG_PREHEAT_SETPOINT    0xA7u
#define VLX_REG_SUPPLY_FAN_STOP     0xA8u
#define VLX_REG_FAN_SPEED_DEFAULT   0xA9u
#define VLX_REG_PROGRAM             0xAAu
#define VLX_REG_SERVICE_MONTHS_LEFT 0xABu
#define VLX_REG_RH_BASIC_LEVEL      0xAEu
#define VLX_REG_BYPASS_SETPOINT     0xAFu
#define VLX_REG_DC_FAN_SUPPLY       0xB0u
#define VLX_REG_DC_FAN_EXHAUST      0xB1u
#define VLX_REG_DEFROST_HYSTERESIS  0xB2u
#define VLX_REG_CO2_SETPOINT_HIGH   0xB3u
#define VLX_REG_CO2_SETPOINT_LOW    0xB4u
#define VLX_REG_PROGRAM_2           0xB5u

// Bits of VLX_REG_STATUS (0xA3). Bits 0..3 are settable, 4..7 are indicators.
#define VLX_STATUS_POWER        (1u << 0)
#define VLX_STATUS_CO2_CONTROL  (1u << 1)
#define VLX_STATUS_RH_CONTROL   (1u << 2)
#define VLX_STATUS_WINTER_MODE  (1u << 3)  // 1 = heat recovery, 0 = summer bypass
#define VLX_STATUS_FILTER       (1u << 4)
#define VLX_STATUS_HEATING      (1u << 5)
#define VLX_STATUS_FAULT        (1u << 6)
#define VLX_STATUS_SERVICE      (1u << 7)

// Bits of VLX_REG_IO_MULTI_2 (0x08)
#define VLX_IO2_DAMPER_SUMMER   (1u << 1)
#define VLX_IO2_FAULT_RELAY     (1u << 2)
#define VLX_IO2_SUPPLY_FAN_OFF  (1u << 3)
#define VLX_IO2_PREHEATING      (1u << 4)
#define VLX_IO2_EXHAUST_FAN_OFF (1u << 5)
#define VLX_IO2_BOOST_SWITCH    (1u << 6)

// Bits of VLX_REG_FLAGS_6 (0x71)
#define VLX_F6_REMOTE_CONTROL   (1u << 4)
#define VLX_F6_BOOST_ACTIVATE   (1u << 5)  // read, set this bit, write back
#define VLX_F6_BOOST_RUNNING    (1u << 6)

// Fault numbers reported in VLX_REG_FAULT (0x36)
typedef enum {
    VLX_FAULT_NONE                 = 0x00,
    VLX_FAULT_SUPPLY_AIR_SENSOR    = 0x05,
    VLX_FAULT_CO2_ALARM            = 0x06,
    VLX_FAULT_OUTDOOR_AIR_SENSOR   = 0x07,
    VLX_FAULT_EXTRACT_AIR_SENSOR   = 0x08,
    VLX_FAULT_WATER_COIL_FROST     = 0x09,
    VLX_FAULT_EXHAUST_AIR_SENSOR   = 0x0A,
} vlx_fault_t;

// ---------------------------------------------------------------------------
// Frames
// ---------------------------------------------------------------------------

typedef struct {
    uint8_t domain;
    uint8_t sender;
    uint8_t receiver;
    uint8_t reg;
    uint8_t value;
    uint8_t checksum;
} vlx_frame_t;

// Low byte of the sum of the first five bytes.
uint8_t vlx_checksum(const uint8_t raw[VLX_FRAME_LEN]);

// Decode six bytes. Returns false if the domain byte or the checksum is wrong;
// out is still filled so a caller can log what was rejected.
bool vlx_frame_decode(const uint8_t raw[VLX_FRAME_LEN], vlx_frame_t *out);
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

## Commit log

2026-08-21 chore: initial project structure
    Scaffolded from the Mironet workspace template: KiCad project layout,
    ESP-IDF firmware skeleton with host-testable core, enclosure folders,
    CI and documentation structure.
2026-08-21 docs(research): protocol, target, measurement plan and risks
    The Vallox DIGIT bus register map is only available as source code in four
    independent implementations, and the manufacturer's protocol PDF could not be
    retrieved. This records the intersection of those four, tags every claim with
    its confidence, and states what has to be measured before any of it can be
    trusted.
    Two findings decide the electrical design and neither is in any document: whether
    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
2026-08-21 docs(research): component candidates, design decisions and project scope
    Parts costed against live JLCPCB stock read on 2026-08-21. The radio module is
    about 60 % of the parts cost, so the two things worth optimising are the module
    choice and the number of distinct Extended parts, not the passives.
    Two selections are argued rather than defaulted. The regulator is picked on
    quiescent current, not price: the Basic wide-input buck idles at 4.4 mA, about
    90 mW at 21 V, on the one rail whose budget is the project's main open risk.
    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
2026-08-21 feat(protocol): Vallox DIGIT codec with host tests
    Replaces the template placeholder parser with the real six-byte telegram codec:
    frame encode and decode, a resynchronising byte-stream parser, the NTC table,
    fan-speed and humidity encodings, a write allow-list and a bus survey.
    Three parts are not transcription of existing work.
    The parser slides one byte at a time to recover alignment, because the telegram
    has no start delimiter. A checksum can therefore pass at the wrong alignment
    about once in 65 000 tries, so frames also have to survive an address sanity
    check before anything believes them.
    The write allow-list has one entry and a test that asserts the count. Vallox
    warns that writin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
    [main.c, vallox_protocol.h]
2026-08-21 feat(tools): vlx-decode, capture analyser for the bus measurement
    Measurement M3 produces a raw byte capture and nothing in it is readable by
    eye. This turns it into annotated telegrams and a census: who was on the bus,
    which registers appeared, which of the two temperature register sets this
    particular machine uses, and which panel address is free.
    Built from firmware/components/vallox_protocol rather than from a second
    implementation. A decoder that disagrees with the firmware is worse than no
    decoder, because it makes the firmware look wrong.
    It also reports what it cannot know. A byte dump has no timestamps, so the
    inter-frame timing that M4 needs still comes from the scope, and the to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
    [vallox_protocol.h]
2026-08-21 docs(security): state the security position before writing the firmware
    Secure boot and flash encryption stay off in the published build, and the
    reason is stated rather than left to look like an oversight: both are one-way
    fuse burns, and a board whose whole premise is that a reader can build one and
    own it should not refuse firmware its owner compiled. Signed OTA images carry
    the weight instead, because they stop a hostile update without taking away the
    owner's ability to flash over USB.
    The residual risk is written down with it. Anyone holding the board can read the
    Wi-Fi credentials out of flash, and for a device inside the owner's own
    ventilation machine that is the right trade — but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
2026-08-21 docs(hardware): say why there is no schematic yet
    An empty hardware directory reads as unfinished. It is a gate: the power stage
    waits on two measurements, and drawing the schematic first would mean drawing
    it twice.
2026-08-21 feat: replace the panel instead of joining the bus
    Testing on the target machine settles it: two controllers on this bus override
    each other. The manufacturer's "up to three panels" holds for three Vallox
    panels, which the mainboard keeps in step by broadcasting to the whole panel
    group, and not for a client that polls on its own schedule. So the original
    panel comes off the wall and this device takes its place.
    That is a bigger change than a decision record. The device is now load bearing:
    if it stops, nothing controls the ventilation. Every setting the panel could
    reach has to be reachable here, which pulls against the one-entry write
    allow-list and resolves as "one measured register at a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
    [main.c, vallox_protocol.h]
2026-08-21 docs(ui): costed display against LEDs, and found the measurement that settles the power budget
    The panel sits under the machine, not on a living-room wall, so there is no
    footprint to match and no aesthetic to preserve. That removes the constraint
    that was driving this and turns it into a question about what the interface is
    for.
    Costed against live stock: LED bar and buttons $0.36, 0.96" OLED $2.55 for the
    finished device, 1.14" colour TFT $3.05 with an unresolved backlight question,
    e-paper unavailable and wrong for a dark room anyway. Only $0.30 of the OLED
    option lands on the assembled board - the display is a bare panel plugged into
    an FPC connector afterwards - so the same board takes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
2026-08-21 docs(ui): 0.96" is too small - revised to a 2.0" colour IPS
    Legibility is angular, not linear: a comfortable character subtends about 20
    arcminutes, so its height is roughly viewing distance over 170. At arm's length,
    where someone stands when they press a button, that is 2.9 mm.
    On a 0.96" OLED that is eight characters by three lines. The display was chosen
    to present a menu of named setpoints - SUPPLY FAN STOP, BYPASS, PREHEAT - and
    eight by three cannot show one. It shows a fan speed and a temperature, which is
    what the LED bar it replaces already did for a tenth of the price.
    The price ladder makes it worse for mono. OLED costs about a dollar per 100 mm2
    and gets worse with size: the 1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
2026-08-21 hw(ui): choose the buttons properly, and find a pin budget while doing it
    The BOM has carried TS-1187A-B-A-B since the LED sketch, but it was carried, not
    chosen: nobody had decided how many buttons, what force, what plunger height, how
    they get actuated through a printed front, or how they reach a microcontroller
    whose pins are nearly all spoken for.
    Four buttons. Minus and plus change fan speed directly on the home screen, which
    is the daily action and what the original panel had dedicated arrows for; OK
    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
2026-08-21 docs(sources): say which datasheets were read and which were only quoted
    CI could not fetch the Analog Devices MAX487 datasheet, and neither could I:
    their server fails HTTP/2 negotiation and times out on HTTP/1.1. The MAX487
    figures therefore come from a search result quoting that datasheet, not from the
    document, and the source rating now says so.
    The tempting fix was to exclude the domain from the link checker and leave the
    rating at 'manufacturer'. That would have been a citation claiming more than it
    had, in a file whose entire purpose is to record exactly how far each claim can
    be trusted. The TI datasheet was genuinely retrieved and read, so the two are now
    rated differently and the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
2026-08-21 chore: add the shared hardware library as a submodule (#2)
    The README has been telling readers to clone with --recurse-submodules since
    the repository was created, but there was nothing to recurse into: mironet-hw-lib
    had no remote, so the reproducibility requirement could not be met and the note
    in docs/pending-submodule.md said so.
    The library is now public at github.com/Miroeilola/mironet-hw-lib and pinned
    here. The library tables under hardware/ will point at ${KIPRJMOD}/lib/mironet-hw-lib
    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
2026-08-21 hw(parts): make library coverage a selection criterion, and change two parts (#3)
    Parts were selected on requirement, price, stock and Basic/Extended class.
    Nothing in that list asked whether a KiCad footprint and a 3D model already
    exist, and checking the shortlist found that the most consequential land pattern
    on the board - the module - had neither.
    Two choices change as a result. ESP32-C3-MINI-1 goes to ESP32-C3-WROOM-02: the
    MINI has no footprint and no model, and the price argument that chose it has
    inverted, from $2.79 against $3.11 to $3.84 against $2.89. TS-1187A goes to
    the 6x6 gullwing land pattern with K2-6639SP-A4SC-04 fitted: the TS-1187A family
    has a footprint but no model, a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
2026-08-21 hw(ui): fit C&K's own switch, and keep USB-C inside the enclosure (#4)
    Two follow-ups from removing price as a constraint on the buttons.
    The switch becomes PTS645SM43SMTR92LFS. Fitting C&K's own part rather than a
    clone does three things at once: 1.6 N restores the force the printed flexure
    wanted, 4.3 mm matches the KiCad 3D model exactly, and KiCad's footprint is
    C&K's own land pattern - so the pad-span check this entry listed as blocking
    stops being a question rather than getting answered. It also gives a second
    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
2026-08-21 hw(sch): rev A schematic on one A3 sheet (#5)
    * hw(sch): empty A3 sheet, title block, library tables — baseline before first symbol
    KiCad-MCP-Checkpoint: true
    Project-Path: hardware
    * hw(sch): rev A schematic, drawn as continuous wires on one A3 sheet
    Drawn ahead of the rail measurements at Miro's request, so that there is
    something concrete to review. The power stage is marked provisional in the
    title block; what M1/M2a can still change is listed in decisions.md and is
    contained in the power region.
    Every connection is a wire from pin to pin. Local labels only name nets; they
    never carry a connection. Power rails use power symbols. ERC with kicad-cli
    10.0.2: 0 errors, 1 warning (Q1's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
    [vallox-rs485-controller.kicad_pcb, vallox-rs485-controller.kicad_sch]
2026-08-23 docs(research): desk evidence and first measurements for M1–M3 (#7)
    * docs(research): desk evidence for M1–M3 before the measurements
    Isolation (M1): the Digit2 SE manual is a vector drawing, not a scan, and at
    600 dpi its diagram shows the panel supply as a separate secondary across
    the core, fused T800 mA. The 12/99 Digit SE guide — the LED-panel generation
    — draws a physically separate 230 V / 16 VAC control transformer; 121 SE
    (2011) and ValloPlus 350 SE (2015, DE) label the same winding 230VAC/16VAC
    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
2026-08-23 hw(pcb): rev A placed, routed and sourced (#6)
    * hw(pcb): rev A placement on a 104 x 66 mm board, not yet routed
    The board file was empty. All 60 schematic parts are now on the top side,
    placed from the netlist with KiCad's bundled pcbnew Python (KiCad closed):
    the MCP server had no pcb_write tools this session and the file-based MCP
    transfer tool is the one the workspace forbids. Every footprint carries its
    symbol UUID as path, so a GUI F8 should reconcile to no changes.
    Floor plan: display glass reserve top-left with the four buttons centred
    under it and the LEDs beside it; FPC connector on the glass's short edge;
    ESP32 module top-right with its antenna 6 mm over the edge, the position t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
    [bare.dsn, parts-revA.csv, vallox-rs485-controller.kicad_pcb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]
2026-08-23 docs(plan): S1 implementation plan — machine emulator, HAL contract, host memory bus (#10)
2026-08-23 feat(sim): S1 — machine emulator, HAL contract and host memory bus (#11)
    * chore: ignore .worktrees/ for local git worktrees
    * feat(hal): panel HAL contract and a host implementation with a memory bus
    The core never touches a UART, a clock or storage; this header is the
    contract every host implements. The host version gives tests a ring-buffer
    bus, a fake clock and a RAM store so a panel and a simulated machine can
    talk in real frames without hardware.
    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
2026-08-23 docs(plan): S2 implementation plan — panel UI core (#13)
    Seven tasks with the code and tests written out; every task's code was
    compiled and run from the document under Apple clang and gcc-15 before
    this commit, and the five views were rendered and inspected. Decisions
    the spec left open (button identity on the ladder, layout constants,
    timeout values, read-only editors for registers off the allow-list,
    language as a stored local setting) are listed at the top.
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2026-08-23 feat(sim): S3 — browser simulator: the UI core in WebAssembly on the rev A GLB, side panel, bus log, Pages (#16)
    * feat(sim): browser host in C — panel_hal for the web, exported sim API, native tests
    The UI core and the machine model get their fourth host: an RGBA framebuffer
    with a dirty-rectangle union, a button ladder fed from clicks (a release is
    honoured only after three samples so a short click in a slow tab still
    debounces), a memory bus between the two with a frame log, and a RAM settings
    store JS mirrors to localStorage. Plain-C exports only; Emscripten flags in the
    Makefile; the same files are tested natively.
    * chore(sim): SPDX header on the simulator Makefile
    * feat(sim):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
    [hal_web.c, sim.c, test_hal_web.c]
2026-08-23 fix(ci): fetch the KiCad 3D models before the GLB export — the container has no packages3D library (#17)
    The kicad/kicad:10.0 container has kicad-cli but not the packages3D library,
    so the first deploy shipped a bare board: every footprint body silently left
    out, only the display module (from lib/) present. tools/fetch-3d-models.py
    reads the model paths from the .kicad_pcb and downloads exactly those files
    from kicad-packages3D at tag 10.0.5 into a cached directory that is passed as
    KICAD10_3DMODEL_DIR. Verified locally: an empty directory reproduces the bare
    export (37 nodes), the fetched one matches the desktop export (142 nodes). The
    smoke test now asserts the SW1..SW4 nodes exist in th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
2026-08-23 mech(enclosure): draft shell, renders, README hero, simulator toggle (#20)
    Parametric two-part enclosure from the routed rev A board (0-collision
    boolean check against the populated pcb.step), product-style renders and a
    seamless exploded-view animation from a reproducible scene, the animation as
    the README hero (labeled a render), and the simulator's Enclosure checkbox
    armed with the draft GLB. Fusion 360 supersedes the STEPs; the scripts remain
    the dimensional record.
    [enclosure-base-draft.step, enclosure-cover-draft.step, m3x8-countersunk-draft.step]
2026-08-23 fix(simulator): visible silkscreen, engraved button glyphs (#21)
    The board rendered without silk/mask because KiCad's GLB export marks every
    material metallic — loadBoard now restores the diffuse for non-metals, the
    same correction the render scene carried. The cover's button markings were
    render decals only; the glyphs are now engraved 0.25 mm into the dish floors
    from a shared geometry source, with coloured inlays in the simulator GLB
    standing in for the print's colour-change layers.
    [enclosure-base-draft.step, enclosure-cover-draft.step]
2026-08-23 test(simulator): align the one 15 s smoke wait with the rest (#22)
    The FAULT-LED wait was the only 15 s timeout among 30-60 s state waits; the
    untouched rerun of the failed main run passed, confirming a flake. Aligned.

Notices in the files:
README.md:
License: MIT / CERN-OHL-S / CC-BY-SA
